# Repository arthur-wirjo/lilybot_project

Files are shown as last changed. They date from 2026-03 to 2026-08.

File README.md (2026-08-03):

lilybot picture



## Lilybot: Omnidirectional Robot with LiDAR-Based Navigation

A custom omnidirectional mobile robot combining ESP32-S3 firmware, micro-ROS, and ROS 2 Nav2 for autonomous indoor navigation.

## Overview

Lilybot is a personal robotics project built to explore the full stack of an autonomous robot from scratch, from mechanical design and PCB design to embedded motor control and ROS 2 navigation.

The original motivation was simple: I wanted to build a small "smart walking table" that could help carry items around, such as bringing water or transporting cooking utensils to my dorm pantry. More importantly, this project became a way for me to learn how to build a complete autonomous robot system myself instead of only working on isolated parts.

The robot uses an ESP32-S3 for low-level control and sensing, and a Raspberry Pi 5 for higher-level ROS 2 tasks such as LiDAR processing, SLAM, localization, and navigation.

---

## Key Features

- Custom omnidirectional chassis
- Custom PCB integrating microcontroller, IMU, motor control, and encoder interfaces
- ESP32-S3-based embedded motor control firmware
- IMU and encoder feedback
- Feedforward control using a 1D lookup table with linear interpolation
- PID wheel speed control
- micro-ROS integration between ESP32-S3 and ROS 2
- LiDAR-based SLAM and Nav2 navigation on Raspberry Pi 5

---

## Hardware

### Main Components

- **Motor:** PG36-3650 geared BLDC motor, 12V rated, 1:50 reduction
- **Wheels:** Generic 75 mm omnidirectional wheels
- **IMU:** MPU6050
- **Computer:** Raspberry Pi 5 running Ubuntu 24.04
- **LiDAR:** RPLIDAR C1
- **Microcontroller:** ESP32-S3 Development Board (N16R8 variant)
- **Battery 1:** Generic 3S Li-Po battery
- **Power Distribution Board:** Generic 12V PDB with 5V output for ESP32
- **Battery 2:** Generic power bank dedicated to Raspberry Pi 5

### Custom PCB

The custom PCB includes:

- ESP32-S3 microcontroller
- IMU
- motor control outputs
- encoder feedback inputs
- two TXS0108E bidirectional level shifters

The level shifters are used because the ESP32 operates at 3.3V logic while the motor interfaces operate at 5V logic.

---

## Note on the Motor Choice

The motors used in this project are inexpensive geared BLDC motors with built-in motor drivers and encoder feedback. They are convenient for prototyping, but the velocity response is noticeably nonlinear under PWM control.

A simple PID controller alone was too slow and resulted in noticeable drift. Adding feedforward improved the response, but drift remained, especially at certain velocity ranges. I also tried a 2nd-order feedforward model with PID, which improved things further but was still not consistent enough across the full operating range.

To address this, I wrote a motor testing program to measure steady-state motor speed at different PWM duty cycles, plotted the results in a spreadsheet, and converted the data into a 1D lookup table. Linear interpolation was then used between table entries to generate the feedforward term. Combined with PID feedback, this gave the most satisfactory real-world performance.

---

## System Architecture

The system is split into two computing layers.

### ESP32-S3

The ESP32-S3 handles low-level real-time tasks:

- encoder reading
- IMU reading
- motor control loop
- odometry calculation
- micro-ROS communication
- publishing odometry-related data
- subscribing to commanded velocity data

### Raspberry Pi 5

The Raspberry Pi 5 handles high-level ROS 2 tasks:

- ROS 2 nodes
- LiDAR reading
- SLAM and localization
- Nav2 planning and control

---

## RTOS Task Structure

To keep the firmware more reliable and responsive, the ESP32-S3 uses both cores for separate responsibilities.

### Core 0: Real-Time Control

Core 0 is dedicated to the low-level control loop. Its tasks include:

- reading encoder pulse counts
- calculating odometry
- converting robot velocity targets into individual wheel targets
- running feedforward + PID wheel speed control
- updating PWM outputs to the motors

### Core 1: Communication and Sensors

Core 1 handles communication-heavy and less timing-critical tasks:

- running the micro-ROS executor
- receiving `cmd_vel` commands
- reading IMU data
- publishing IMU and odometry messages to ROS 2 over UART

This separation helped keep the control loop more stable while still maintaining communication with the Raspberry Pi.

---

## Setup

These instructions assume the Raspberry Pi 5 is running Ubuntu 24.04 and development is done over SSH.

### 1. Clone the Repository

```bash
cd ~
git clone https://github.com/arthur-wirjo/lilybot_project.git
```

---

### 2. Install ESP-IDF

Lilybot firmware is developed using ESP-IDF.

Install prerequisites:

```bash
sudo apt-get update
sudo apt-get install git wget flex bison gperf python3 python3-venv cmake ninja-build ccache libffi-dev libssl-dev dfu-util libusb-1.0-0
```

Clone ESP-IDF:

```bash
mkdir -p ~/esp
cd ~/esp
git clone -b v6.0.2 --recursive https://github.com/espressif/esp-idf.git
```

Install the toolchain:

```bash
cd ~/esp/esp-idf
./install.sh esp32
```

Export the environment:

```bash
. $HOME/esp/esp-idf/export.sh
```

Optionally, add this alias to `~/.bashrc` for convenience:

```bash
alias get_idf='. $HOME/esp/esp-idf/export.sh'
```

Then reload:

```bash
source ~/.bashrc
```

---

### 3. Flash the ESP32-S3 Firmware

In one terminal:

```bash
cd ~/lilybot_project/firmware_esp32s3/micro-ROS
idf.py flash monitor
```

---

### 4. Run the micro-ROS Agent

In another terminal:

```bash
cd ~/lilybot_project/firmware_esp32s3
docker run -it --rm -v /dev:/dev --privileged --net=host microros/micro-ros-agent:jazzy serial --dev /dev/ttyAMA0 -b 115200
```

Alternatively:

```bash
./run_microros_agent.sh
```

---

### 5. Build the ROS 2 Workspace

In another terminal:

```bash
cd ~/lilybot_project/ros2_ws
colcon build
```

---

### 6. Run the ROS 2 Stack

The main setup commands are:

```bash
ros2 launch my_robot_description rsp.launch.py
ros2 run foxglove_bridge foxglove_bridge
ros2 launch sllidar_ros2 sllidar_c1_launch.py serial_port:=/dev/ttyUSB0
ros2 run robot_localization ekf_node --ros-args --params-file src/lilybot_localization/config/ekf.yaml
ros2 launch slam_toolbox online_async_launch.py slam_params_file:=src/lilybot_localization/config/mapper_params.yaml
ros2 launch nav2_bringup bringup_launch.py use_sim_time:=False autostart:=True map:=src/lilybot_navigation/dorm_map.yaml params_file:=src/lilybot_navigation/config/custom_nav2_params.yaml
ros2 run nav2_map_server map_saver_cli -f src/lilybot_navigation/dorm_map
```

Additional setup commands are documented in the repository.

---

## Implementation Notes

This project was built solo, including:

- mechanical design
- PCB design
- embedded firmware
- control implementation
- ROS 2 integration
- robot assembly and testing

---

## Challenges and Lessons Learned

### Nonlinear Motor Behavior

One of the main challenges was achieving stable and consistent wheel speed control using low-cost motors with nonlinear PWM-to-speed behavior.

The progression was roughly:

1. PID only  
2. feedforward + PID  
3. 2nd-order feedforward + PID  
4. 1D lookup table feedforward + PID

The lookup-table-based feedforward gave the best results in practice.

### Noisy Encoder-Derived Odometry

Encoder-based odometry was noisier than expected, especially due to the characteristics of the motors and drivetrain. This made low-pass filtering important for producing more stable velocity and odometry estimates.

### Multi-Core Task Separation

Using both ESP32 cores helped keep the real-time motor control loop more reliable while offloading communication and sensor publishing to the other core.

### PCB Design Retrospective

Looking back with more hardware experience from my later DIY FOC controller project, I would have used a ground copper pour instead of manually routing ground traces point-to-point. In this case the board was simple and low power, so it still worked acceptably, but it was still not the best layout practice.

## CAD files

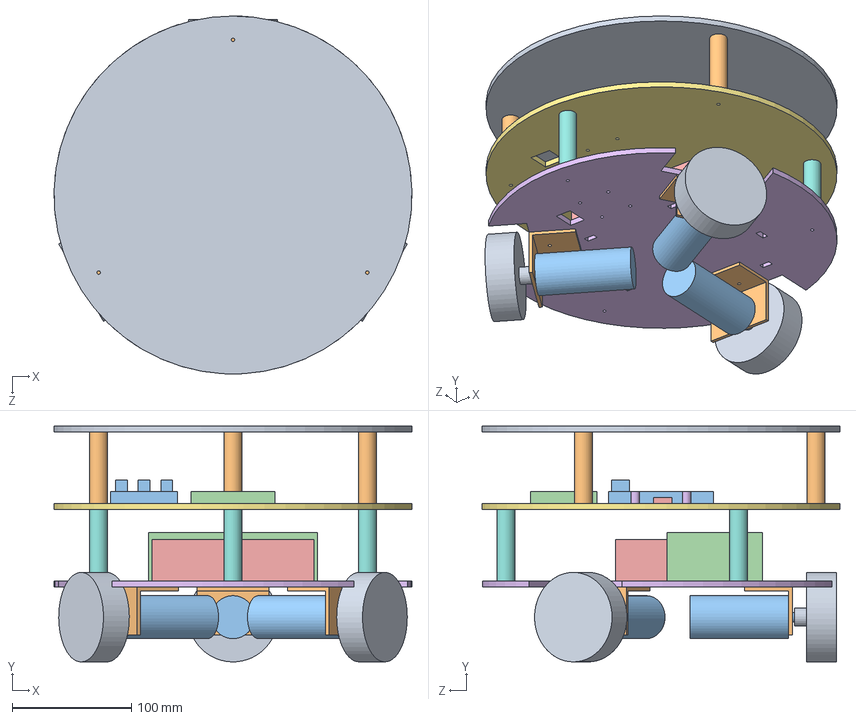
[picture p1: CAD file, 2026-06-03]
mechanical/Lilithbot V3 Assembly.SLDASM
300.0 x 197.6 x 300.0 mm
Base Layer 1
Li-Po Battery
Power Bank
motor x 3
motor bracket x 3
wheel x 3
Standoff Layer 1 x 3
Base Layer 2
10mm standoff x 4
IMU
PCB
Raspberry Pi 5
Standoff Layer 2 x 3
Base Layer 3

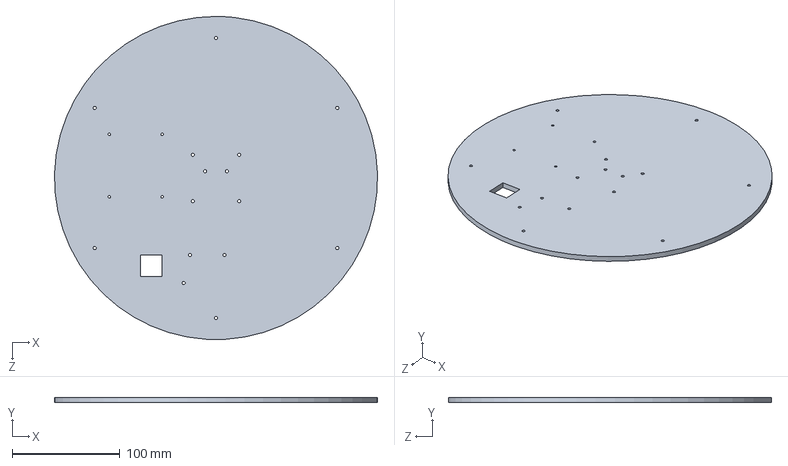
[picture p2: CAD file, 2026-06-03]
mechanical/Base Layer 2.SLDPRT
299.9 x 5.00 x 300.0 mm

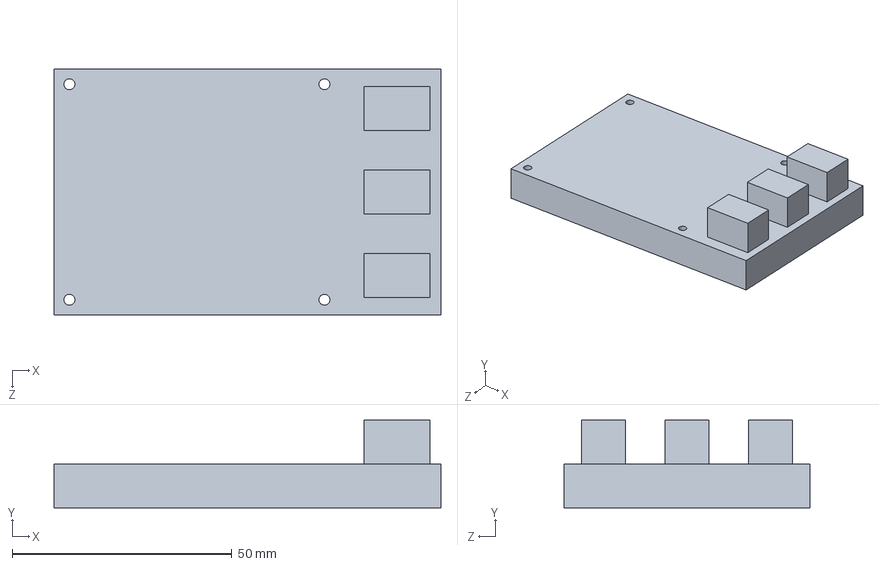
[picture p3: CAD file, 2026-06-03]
mechanical/Raspberry Pi 5.SLDPRT
88.0 x 20.0 x 56.0 mm

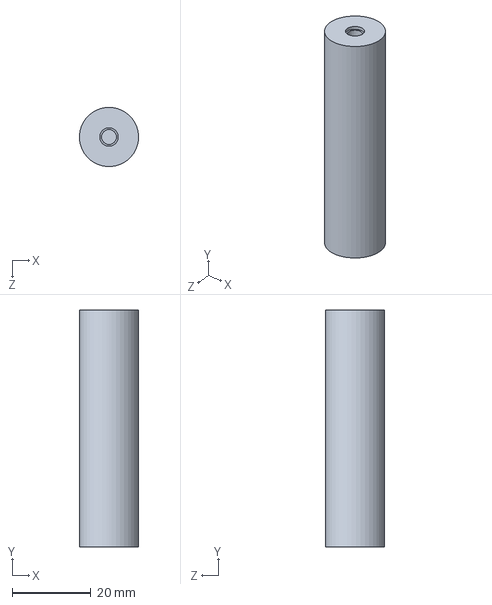
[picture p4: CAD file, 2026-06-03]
mechanical/Standoff Layer 1.SLDPRT
15.0 x 60.0 x 15.0 mm

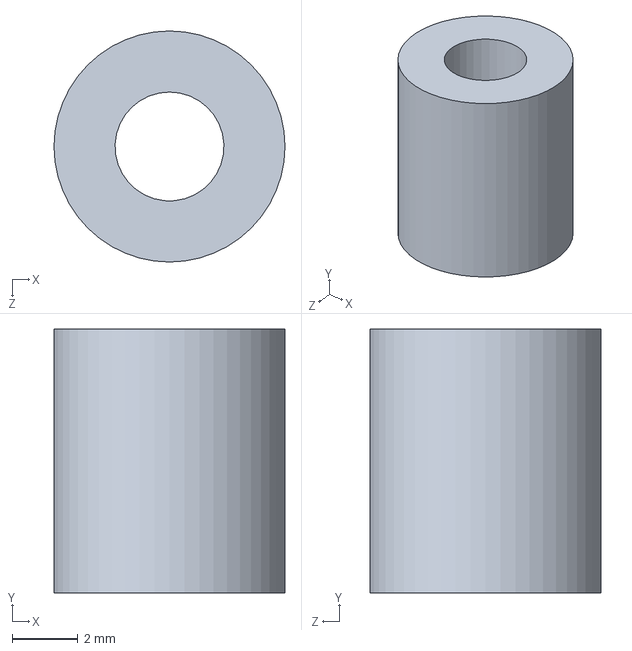
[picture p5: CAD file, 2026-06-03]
mechanical/8mm standoff.SLDPRT
7.00 x 8.00 x 7.00 mm

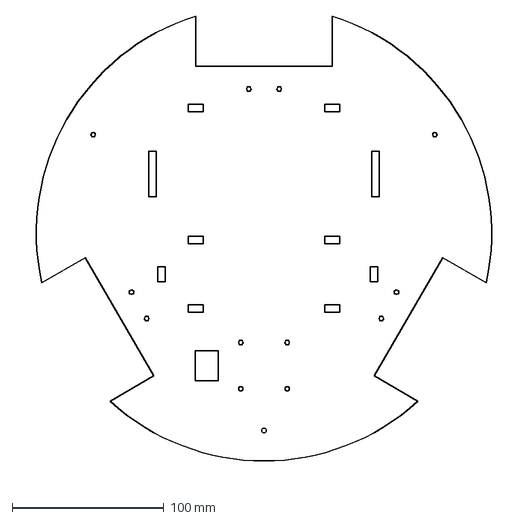
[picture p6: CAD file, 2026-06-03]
mechanical/Base Layer 1 drawing.DXF
326.7 x 306.3 mm

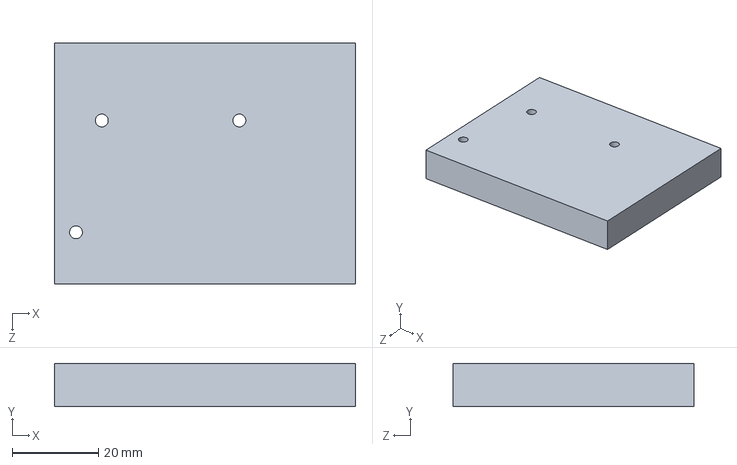
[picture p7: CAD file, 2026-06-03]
mechanical/PCB.SLDPRT
70.0 x 10.0 x 56.0 mm

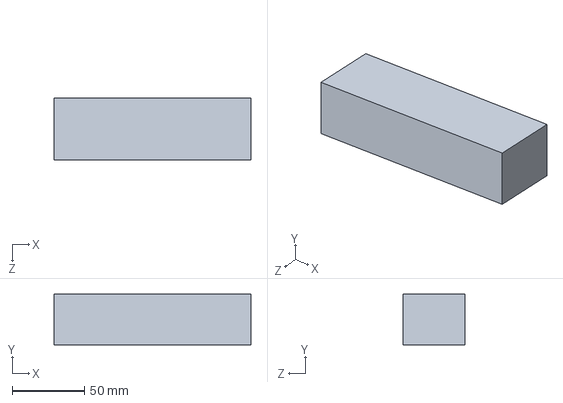
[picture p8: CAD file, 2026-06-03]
mechanical/Li-Po Battery.SLDPRT
136.0 x 35.0 x 43.0 mm

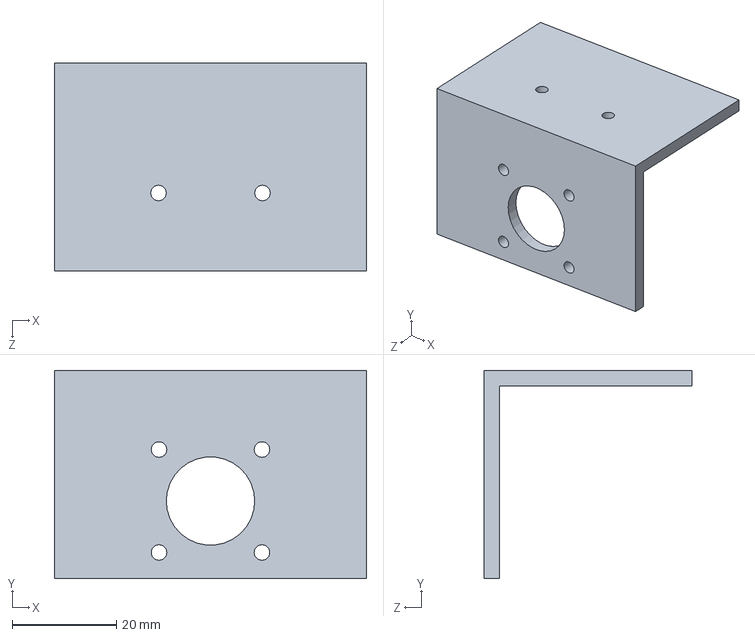
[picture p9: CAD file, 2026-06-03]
mechanical/motor bracket.SLDPRT
60.0 x 40.0 x 40.0 mm

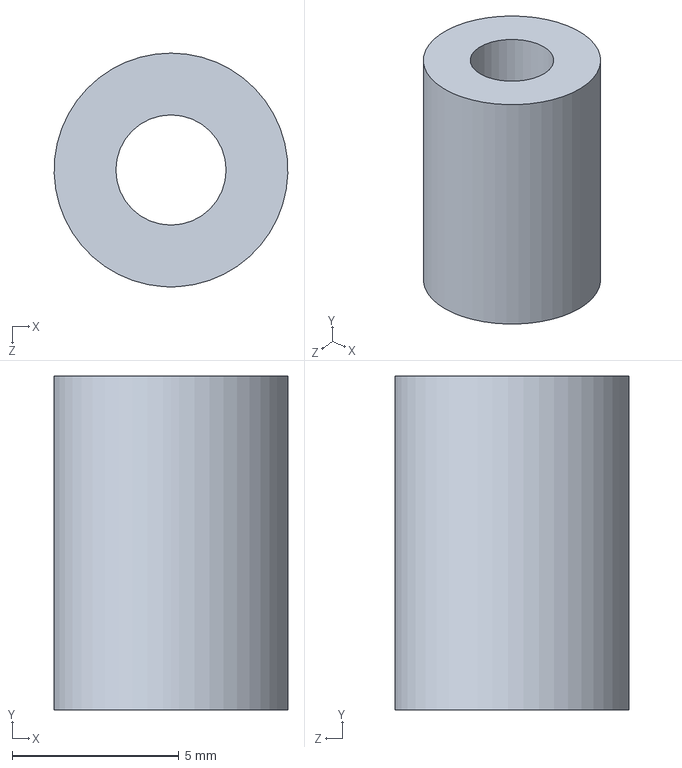
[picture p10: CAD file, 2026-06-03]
mechanical/10mm standoff.SLDPRT
7.00 x 10.0 x 7.00 mm

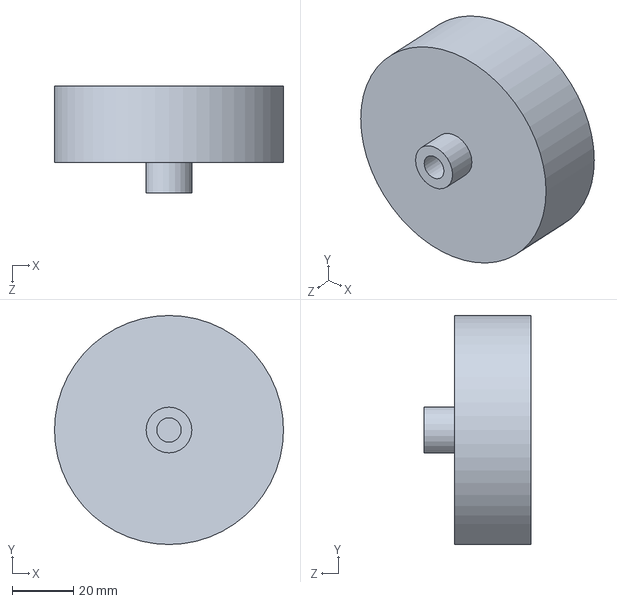
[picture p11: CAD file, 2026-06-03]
mechanical/wheel.SLDPRT
75.0 x 75.0 x 35.0 mm

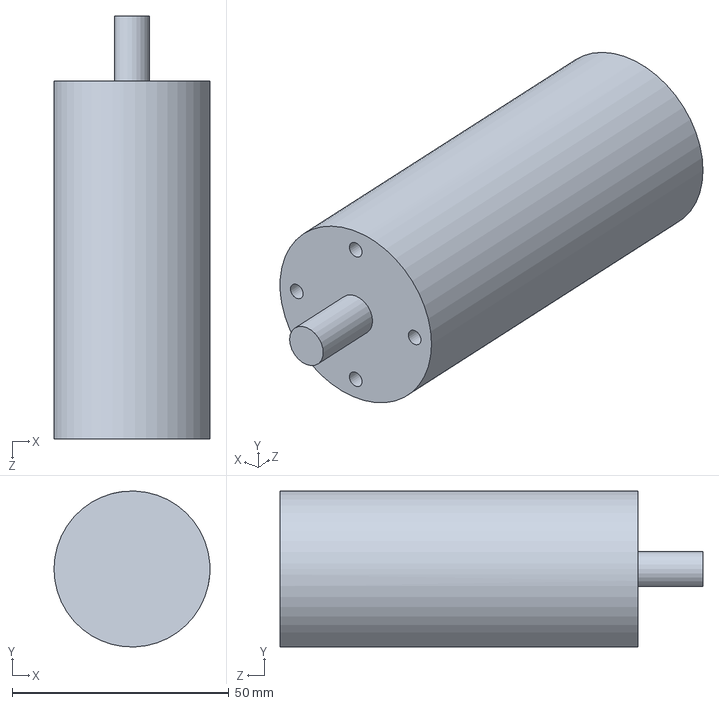
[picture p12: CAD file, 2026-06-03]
mechanical/motor.SLDPRT
36.0 x 36.0 x 97.6 mm

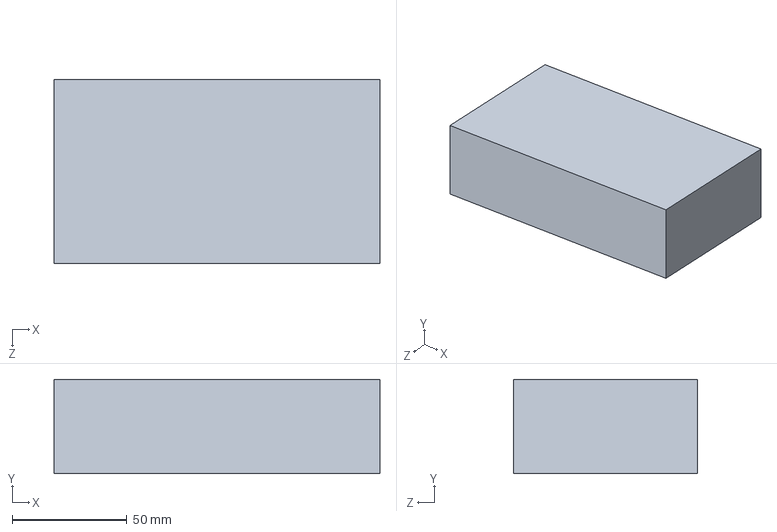
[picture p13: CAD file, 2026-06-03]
mechanical/Power Bank.SLDPRT
142.0 x 41.0 x 80.0 mm

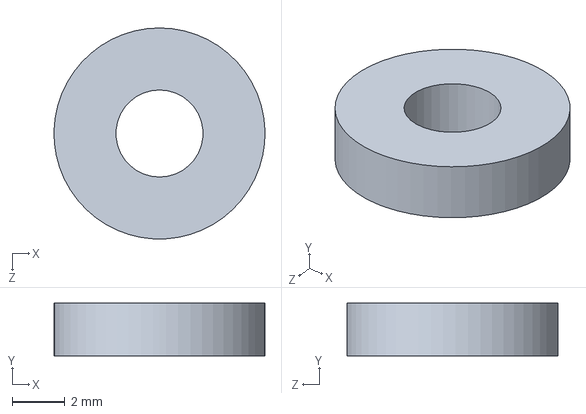
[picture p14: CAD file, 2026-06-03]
mechanical/spacer for PDB.SLDPRT
8.00 x 2.00 x 8.00 mm

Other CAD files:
mechanical/Base Layer 3.SLDPRT
mechanical/Standoff Layer 2.SLDPRT
mechanical/IMU.SLDPRT
mechanical/Base Layer 1.SLDPRT
mechanical/Lidar Sensor.SLDPRT
mechanical/PDB.SLDPRT
mechanical/motor bracket drawing.SLDDRW

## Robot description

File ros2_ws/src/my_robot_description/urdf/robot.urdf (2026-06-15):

<?xml version="1.0"?>
<robot name="lilybot">

    <link name="base_footprint"/>

    <link name="base_link">
        <visual>
            <geometry>
                <cylinder radius="0.15" length="0.07"/>
            </geometry>
            <material name="blue">
                <color rgba="0 0 1 1"/>
            </material>
        </visual>
    </link>

    <joint name="base_joint" type="fixed">
        <parent link="base_footprint"/>
        <child link="base_link"/>
        <origin xyz="0 0 0.0976" rpy="0 0 0"/>
    </joint>

    <link name="laser">
        <visual>
            <geometry>
                <cylinder radius="0.025" length="0.018"/>
            </geometry>
            <material name="black">
                <color rgba="0 0 0 1"/>
            </material>
        </visual>
    </link>

    <link name="laser_mount">
        <visual>
            <geometry>
                <box size="0.056 0.056 0.033"/>
            </geometry>
            <material name="grey">
                <color rgba="0.5 0.5 0.5"/>
            </material>
        </visual>
    </link>

    <joint name="laser_mount_joint" type="fixed">
        <parent link="base_link"/>
        <child link="laser_mount"/>
        <origin xyz="0 0 0.05155" rpy="0 0 0"/>
    </joint>

    <joint name="laser_joint" type="fixed">
        <parent link="laser_mount"/>
        <child link="laser"/>
        <origin xyz="0 0 0.02565" rpy="0 0 3.14159"/>
    </joint>

    <link name="wheel_1">
        <visual>
            <geometry>
                <cylinder radius="0.0375" length="0.025"/>
            </geometry>
        </visual>
        <material name="red">
            <color rgba="1 0 0 1"/>
        </material>
    </link>

    <!-- wheel 1 = front left -->
    <joint name="wheel_1_joint" type="continuous">
        <parent link="base_link"/>
        <child link="wheel_1"/>
        <origin xyz="0.06725 0.11648 -0.0601" rpy="1.5708 0 2.61799"/>
    </joint>

    <!-- wheel 2 = front right -->
    <link name="wheel_2">
        <visual>
            <geometry>
                <cylinder radius="0.0375" length="0.025"/>
            </geometry>
        </visual>
        <material name="red">
            <color rgba="1 0 0 1"/>
        </material>
    </link>

    <!-- wheel 3 = back -->
    <joint name="wheel_2_joint" type="continuous">
        <parent link="base_link"/>
        <child link="wheel_2"/>
        <origin xyz="0.06725 -0.11648 -0.0601" rpy="1.5708 0 0.52359"/>
    </joint>

    <link name="wheel_3">
        <visual>
            <geometry>
                <cylinder radius="0.0375" length="0.025"/>
            </geometry>
        </visual>
        <material name="red">
            <color rgba="1 0 0 1"/>
        </material>
    </link>

    <joint name="wheel_3_joint" type="continuous"> 
        <parent link="base_link"/>
        <child link="wheel_3"/>
        <origin xyz="-0.1345 0.0 -0.0601" rpy="1.5708 0 -1.5708"/> 
    </joint>

</robot>

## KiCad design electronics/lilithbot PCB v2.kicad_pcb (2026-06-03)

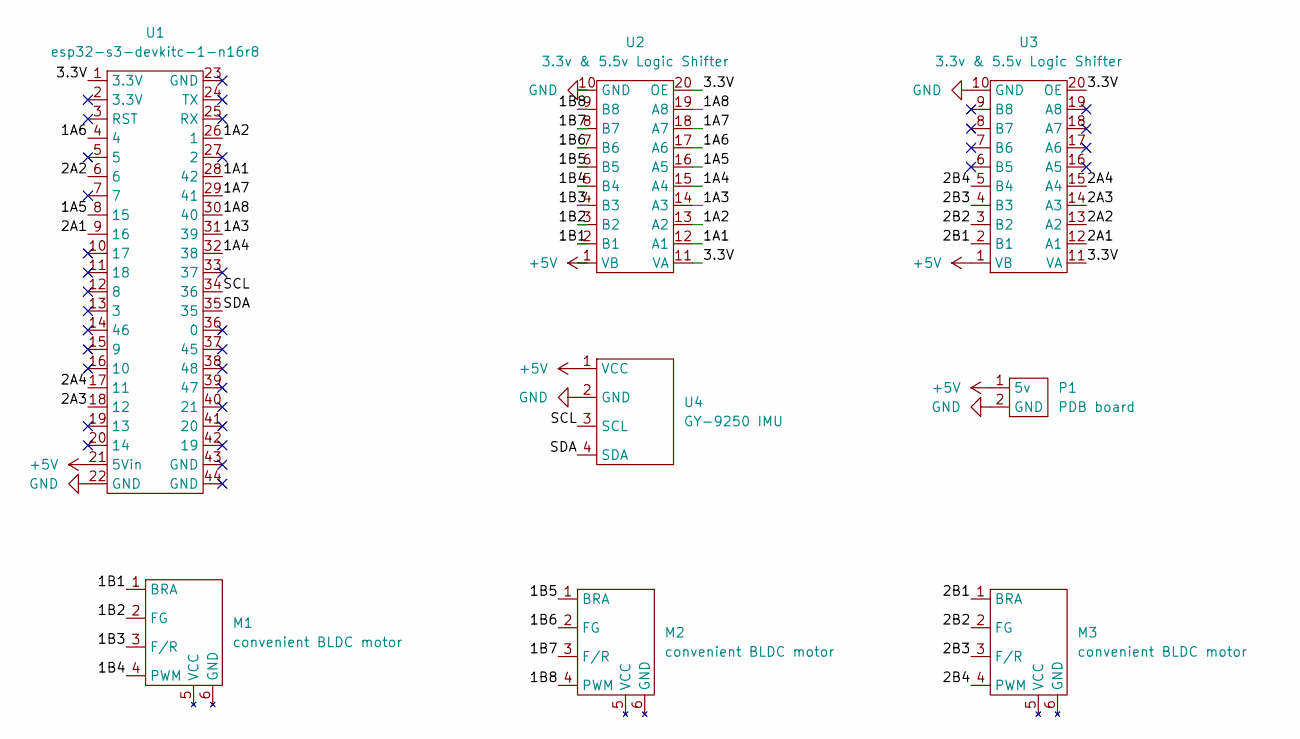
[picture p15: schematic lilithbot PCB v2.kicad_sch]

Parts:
M1, M2, M3: convenient BLDC motor; BDLC Motor
P1: PDB board; PDB
U1: esp32-s3-devkitc-1-n16r8
U2, U3: 3.3v & 5.5v Logic Shifter; Logic Shifter
U4: GY-9250 IMU; imu

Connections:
+5V: P1.1 (5v), U1.21 (5Vin), U2.1 (VB), U3.1 (VB), U4.1 (VCC)
/1A1: U1.28 (42), U2.12 (A1)
/1A2: U1.26 (1), U2.13 (A2)
/1A3: U1.31 (39), U2.14 (A3)
/1A4: U1.32 (38), U2.15 (A4)
/1A5: U1.8 (15), U2.16 (A5)
/1A6: U1.4, U2.17 (A6)
/1A7: U1.29 (41), U2.18 (A7)
/1A8: U1.30 (40), U2.19 (A8)
/1B1: M1.1 (BRA), U2.2 (B1)
/1B2: M1.2 (FG), U2.3 (B2)
/1B3: M1.3 (F/R), U2.4 (B3)
/1B4: M1.4 (PWM), U2.5 (B4)
/1B5: M2.1 (BRA), U2.6 (B5)
/1B6: M2.2 (FG), U2.7 (B6)
/1B7: M2.3 (F/R), U2.8 (B7)
/1B8: M2.4 (PWM), U2.9 (B8)
/2A1: U1.9 (16), U3.12 (A1)
/2A2: U1.6, U3.13 (A2)
/2A3: U1.18 (12), U3.14 (A3)
/2A4: U1.17 (11), U3.15 (A4)
/2B1: M3.1 (BRA), U3.2 (B1)
/2B2: M3.2 (FG), U3.3 (B2)
/2B3: M3.3 (F/R), U3.4 (B3)
/2B4: M3.4 (PWM), U3.5 (B4)
/3.3V: U1.1 (3.3V), U2.11 (VA), U2.20 (OE), U3.11 (VA), U3.20 (OE)
/SCL: U1.34 (36), U4.3 (SCL)
/SDA: U1.35, U4.4 (SDA)
GND: P1.2 (GND), U1.22 (GND), U2.10 (GND), U3.10 (GND), U4.2 (GND)

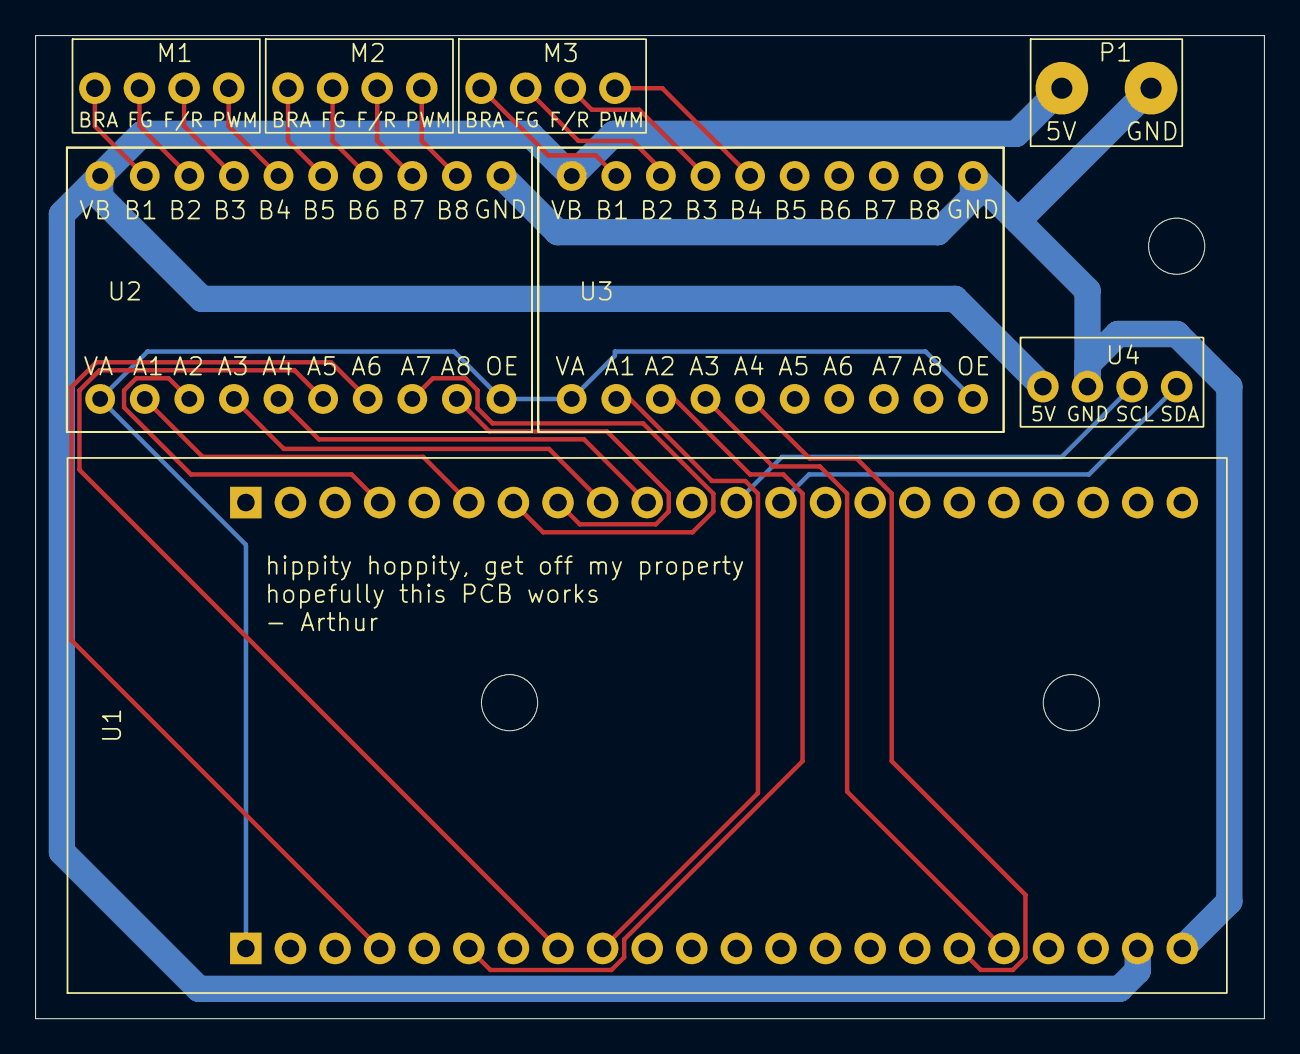
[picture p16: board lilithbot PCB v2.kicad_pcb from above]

Board: 2 copper layers, 70.0 x 56.0 mm, 8 parts (0 on the bottom side), 29 nets.

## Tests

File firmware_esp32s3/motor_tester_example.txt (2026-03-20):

stty -F /dev/ttyAMA0 115200
echo "m1 50" > /dev/ttyAMA0

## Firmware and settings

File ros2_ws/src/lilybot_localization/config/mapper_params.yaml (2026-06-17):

slam_toolbox:
  ros__parameters:
    # Frame Names
    odom_frame: odom
    map_frame: map
    base_frame: base_link
    scan_topic: /scan

    # Time and Tolerance
    use_sim_time: false
    transform_timeout: 0.5
    tf_buffer_duration: 5.0

    # Mapping setting for a small dorm room
    resolution: 0.05
    max_laser_range: 5.0 # RPLiDAR C1 Range
    minimum_time_interval: 0.5
    minimum_travel_distance: 0.1
    minimum_travel_heading: 0.1

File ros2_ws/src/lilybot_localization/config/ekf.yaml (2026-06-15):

ekf_filter_node:
  ros__parameters:
    frequency: 30.0 
    sensor_timeout: 0.1
    two_d_mode: true
    publish_tf: true
    transform_time_offset: 0.0
    transform_timeout: 0.0
    print_diagnostics: true
    debug: false

    map_frame: map
    odom_frame: odom
    base_link_frame: base_link
    world_frame: odom

    odom0: /odom
    odom0_config: [false, false, false, #x,y,z position
                   false, false, false, #r,p,y orientation
                   true, true, false,    #x,y,z velocity
                   false, false, true, #r,p,y velocity
                   false, false, false] #x,y,z acceleration
    odom0_queue_size: 10
    odom0_nodelay: true
    odom0_differential: false
    odom0_relative: false

    imu0: /imu/data
    imu0_config: [false, false, false,
                  false, false, false, 
                  false, false, false,
                  false, false, true, #yaw velocity
                  true, true, false]  #x,y acceleration
    imu0_nodelay: true
    imu0_differential: false
    imu0_relative: false
    imu0_queue_size: 10

    imu0_remove_gravitational_acceleration: true

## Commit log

2026-03-09 fixed IMU pubishing issue because of incorrect bracketing in while loop
2026-03-10 removed old project for testing usb serial in micro-ROS but now uart is used so its not needed
2026-03-10 making a new esp-idf project for testing motor
2026-03-11 finsihed motor tester and its working perfectly and command is sent using uart initally for micro-ROS
2026-03-15 motor control part in progree, editing motor_tester.c to check for encoder and max wheel speed
2026-03-20 added and fixed motor_tester
    [motor_tester.c]
2026-03-20 finished adding motor_control to micro-ROS, will test and readjust later
2026-04-08 fixed bugs for motor control task
2026-04-15 fixed minor bug and tested the motor. works but very jiterry and innacurate
2026-04-16 added feedforward addition control, low-pass filter for odometry, derivative-on-measurement for pid
2026-05-04 edited motor_tester so that it detects rising and falling edge for better encoder feedback for calibration
2026-05-27 successfully fixed drifting problem by reducing the max speed and adding anti-windup and tuning PID and adding feedforward contro. currently there is a huge acceleration in the beginning leading to s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
2026-06-03 added the whole thing instead of just firmware
    [10mm standoff.SLDPRT, 8mm standoff.SLDPRT, Base Layer 1 drawing.DXF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]
2026-06-03 added urdf and gitignores
    [robot.urdf]
2026-06-06 added second order feedforward control for better motor control
2026-06-06 added 1D lookup table with linear interpolation for better feedforward reponse motor control
2026-06-15 added ros2 packages for URDF, LiDAR, EKF and SLAM. Next job is to fix the orientation of odometry of micro-ROS to match the orientation of LiDAR
    [ekf.yaml]
2026-06-15 fixed the orientation conflict between IMU and LiDAR for odometry and localization
    [robot.urdf]
2026-08-03 fixed electronics directory name mispell
    [lilithbot PCB v2-B_Cu.gbr, lilithbot PCB v2-B_Mask.gbr, lilithbot PCB v2-B_Paste.gbr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]
